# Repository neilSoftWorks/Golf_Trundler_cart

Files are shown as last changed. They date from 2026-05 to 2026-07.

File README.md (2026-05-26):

# Golf Cart Receiver (The Brain)

This firmware runs on the **ESP32-S3 SuperMini attached to the Hoverboard**. It acts as the "Software Defined" brain of the vehicle, managing motor logic, safety, and a professional diagnostic display.

## Key Features
*   **Transparent Driver Model:** The Hoverboard acts as a dumb driver; all mixing and tuning logic lives on the ESP32.
*   **Dynamic Tuning:** Adjust Torque (Amps) and Smoothing (Inertia) in real-time without re-flashing.
*   **Active Hill Hold:** Long-press STOP triggers an active PID-lock for rock-solid parking on slopes.
*   **Dual Mode:**
    1.  **Manual Mode:** Control speed/steer via integrated 5-button set.
    2.  **Remote Mode:** Broadcast mirror control from the handheld remote (ESP-NOW).
*   **Integrated UI:** 240x320 ST7789 display with high-quality GFX fonts and a professional battery footer.
*   **Safety First:**
    *   **Reverse Limit:** Hard-limited to speed '10' with visual orange warning.
    *   **Button Lock:** Speed setpoint frozen while Parked or Braked.
    *   **Watchdog:** Auto-stops if communication or remote link is lost.

## Wiring (See `gemini.md` for full details)
*   **UART:** GPIO 44 (RX) / 43 (TX) -> Hoverboard.
*   **Buttons:** FWD (12), REV (5), STOP (1), LEFT (10), RIGHT (11).
*   **Display (SPI):** SCK (6), MOSI (4), CS (7), DC (2), RST (3).

## How to Flash
See the comprehensive [FLASHING_GUIDE.md](../FLASHING_GUIDE.md) in the root directory for step-by-step instructions.

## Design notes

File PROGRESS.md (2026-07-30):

# Golf Trundler Progress (Cart Side)

## 1. Hardware Status
- [x] **Comms:** UART @ 19200 baud (GPIO 44/43).
- [x] **Control Mode:** **TRANSPARENT MOTOR DRIVER**.
    - ESP32 handles all Tank Mixing, Inversions, and Speed Synchronization.
    - Hoverboard Master/Slave updated to accept dynamic Mode, Torque, and Inertia.
- [x] **Display:** **INTEGRATED ST7789**. 
    - Professional GFX fonts (FreeSans, BigFont).
    - Battery Icon and Footer.
    - User / Dev dual-screen toggle.
- [x] **Manual Control:** 5-Button Integrated Set (GPIO 1, 5, 10, 11, 12).
- [x] **Wireless:** **UNIFIED CONTROL** (ESP-NOW Paired Link).
    - Hardcoded MAC Pairing established.
    - Dual-control merging (Logical OR of all buttons).

## 2. Firmware Features
### A. "Smart Manual" Mode
- **Active Hill Hold:** Long-press STOP triggers **Mode 1 (PID)** at speed 0 for absolute wheel lock.
- **Dynamic Tuning:** Current limit and Inertia are now adjustable via ESP32.
- **Visual Feedback:** Bold User Screen with color-coded directional warnings.
- **Dev Terminal:** Double-click STOP to view real-time RPM, Voltage, and Sync factors.
- **Beeper:** Reverse beep disabled.
- **Auto-Shutdown:** Disabled (unit stays active for long test sessions).

### B. Safety
- **Reverse Limit:** Hard-limited to user-speed "20" (-350 internal).
- **Forward Limit:** Hard-limited to user-speed "30" (525 internal).
- **Interlock:** Speed cannot be changed while Parked or Braked.
- **Remote Timeout:** Remote commands ignored if link lost for >1s.

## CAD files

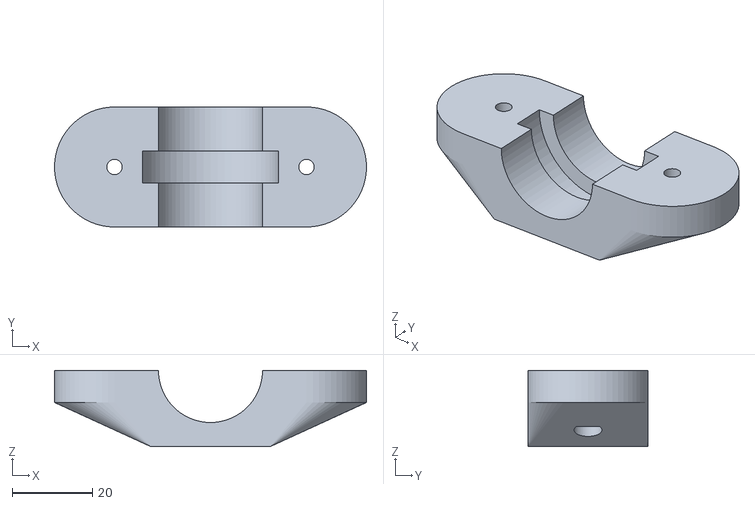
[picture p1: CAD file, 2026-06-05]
CAD/Clamp_B_Mount26.stl
78.0 x 30.0 x 19.0

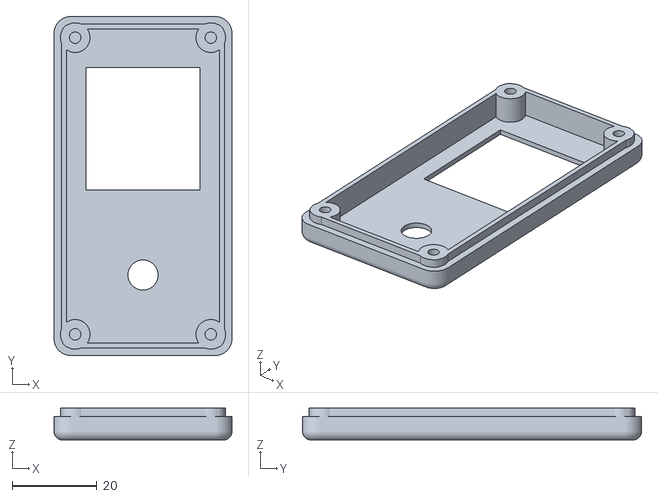
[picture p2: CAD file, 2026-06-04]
CAD/comboMount26T.stl
42.0 x 80.0 x 7.50

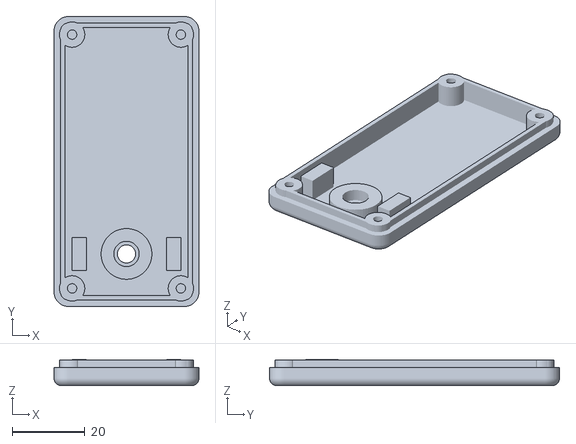
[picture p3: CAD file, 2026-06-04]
CAD/RemoteLid.stl
40.0 x 80.0 x 7.20

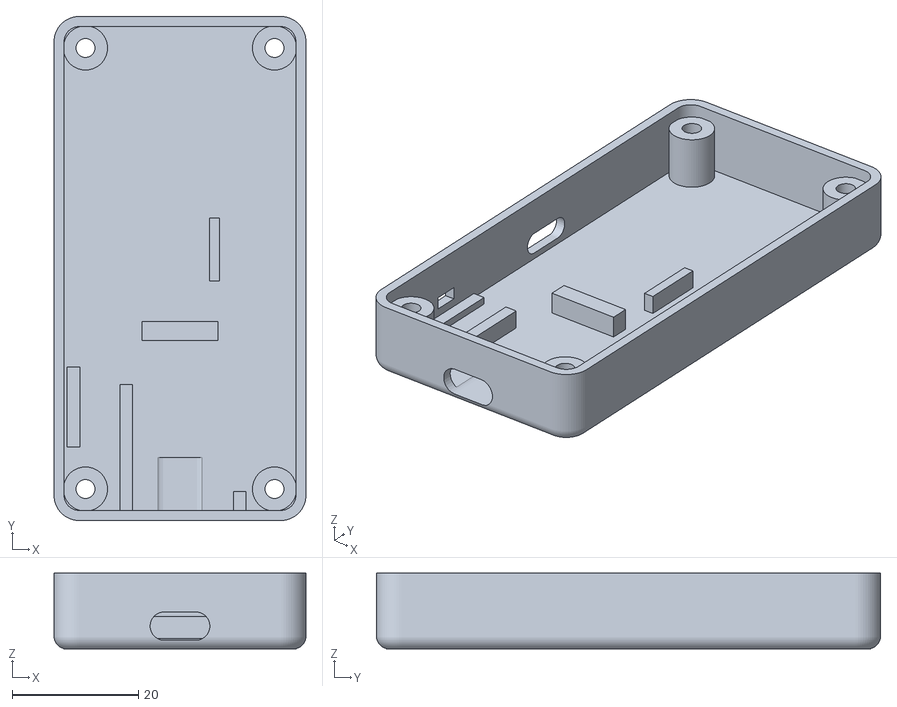
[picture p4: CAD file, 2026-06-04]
CAD/RemoteBase.stl
40.0 x 80.0 x 12.0

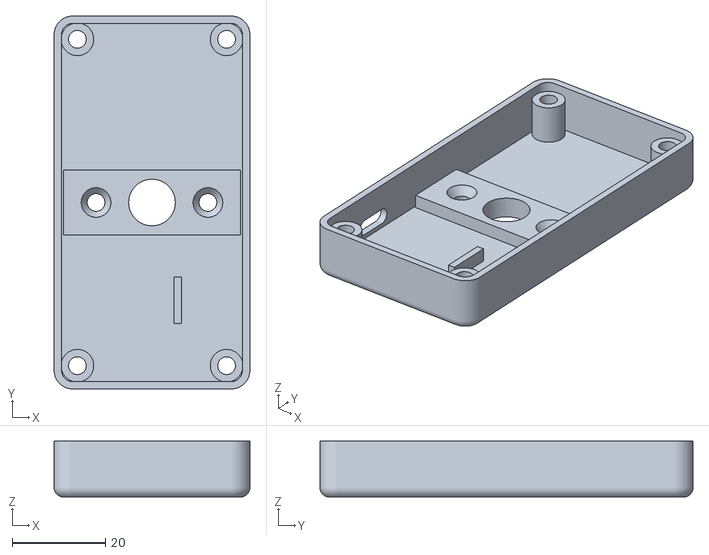
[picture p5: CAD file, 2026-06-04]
CAD/comboMount26B.stl
42.0 x 80.0 x 12.0

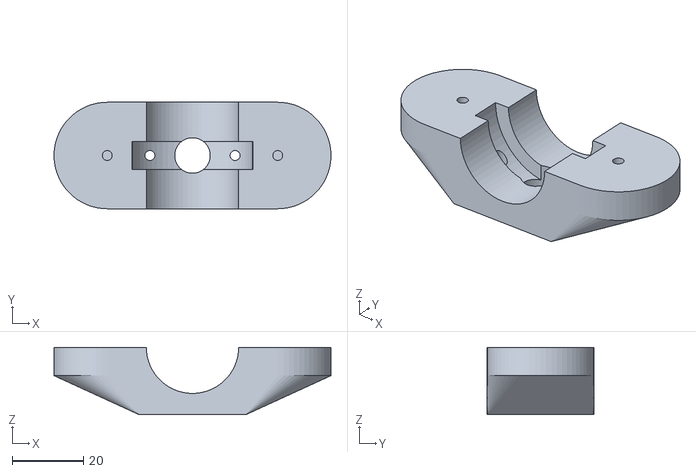
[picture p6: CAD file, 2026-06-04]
CAD/Clamp_T_Mount26.stl
78.0 x 30.0 x 19.0

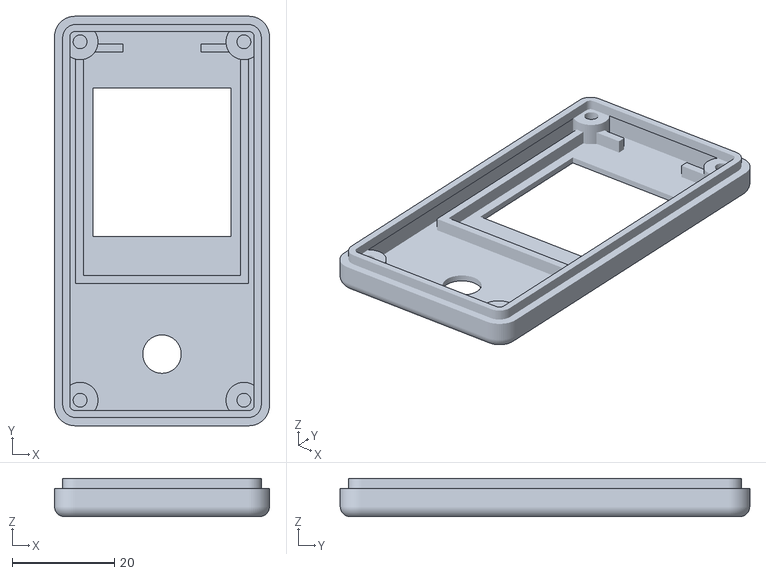
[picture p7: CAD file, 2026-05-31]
CAD/comboMount_lid.stl
42.0 x 80.0 x 7.50

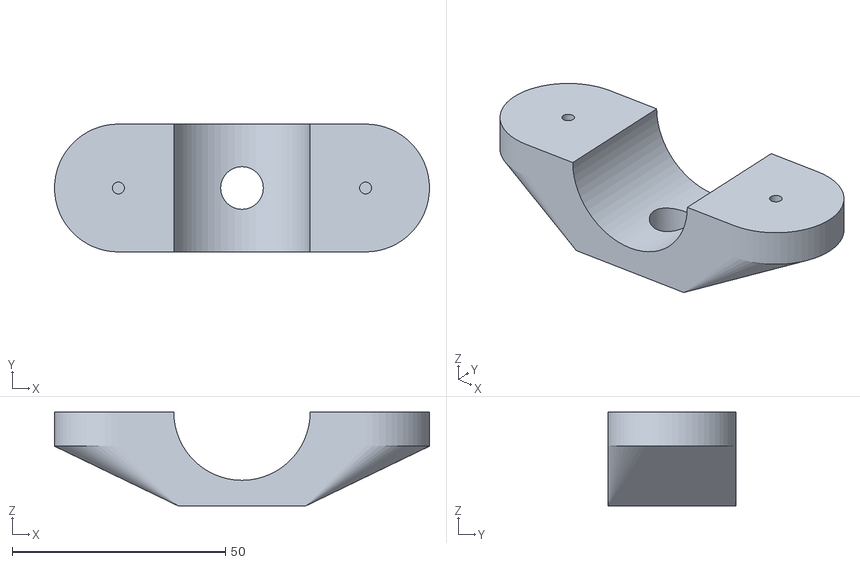
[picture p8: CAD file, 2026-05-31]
CAD/comboMount2.stl
88.0 x 30.0 x 22.0

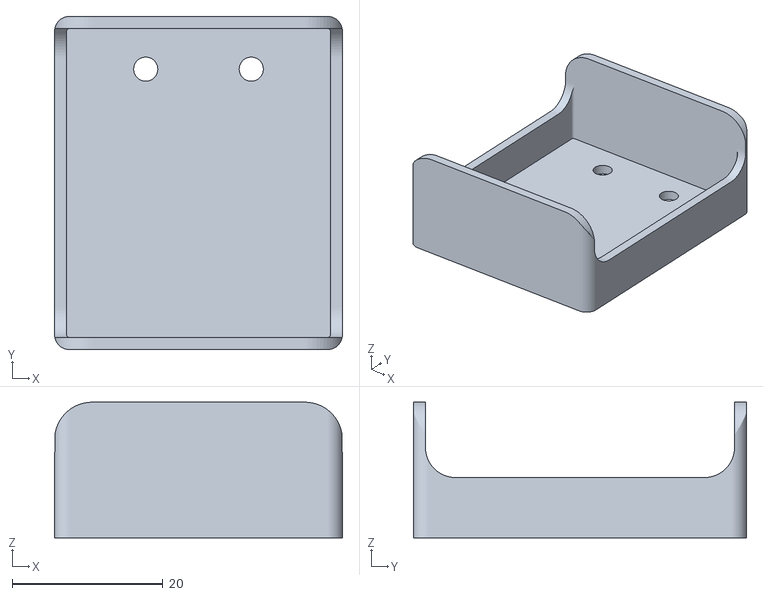
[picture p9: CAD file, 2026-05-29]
CAD/ShotScopeMount.stl
38.2 x 44.2 x 18.0

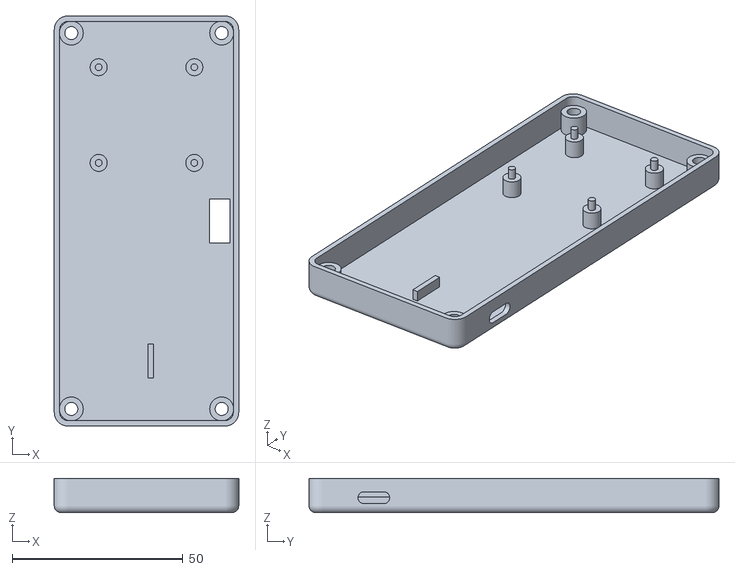
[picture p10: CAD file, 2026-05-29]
CAD/Cart_Controller_base.stl
54.0 x 120.0 x 10.0

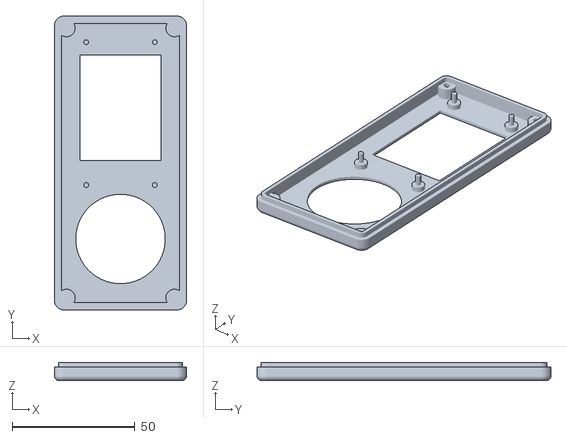
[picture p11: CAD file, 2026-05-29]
CAD/Cart_Controller_lid.stl
54.0 x 120.0 x 7.50

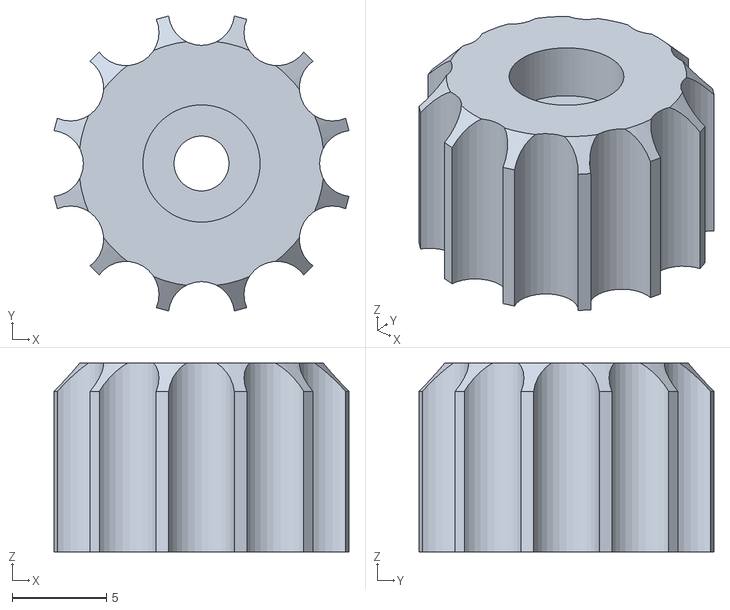
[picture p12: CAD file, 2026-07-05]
CAD/ThumbScrew.stl
15.6 x 15.6 x 10.0

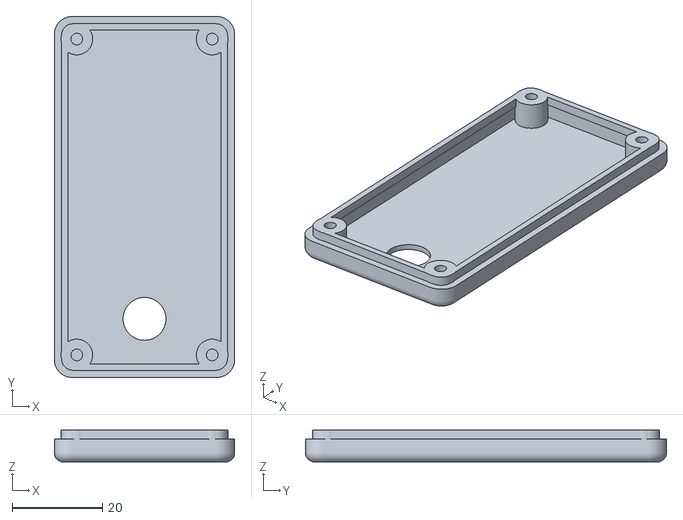
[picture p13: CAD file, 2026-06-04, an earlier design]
CAD/Archive/Remote80T.stl
40.0 x 80.0 x 7.00

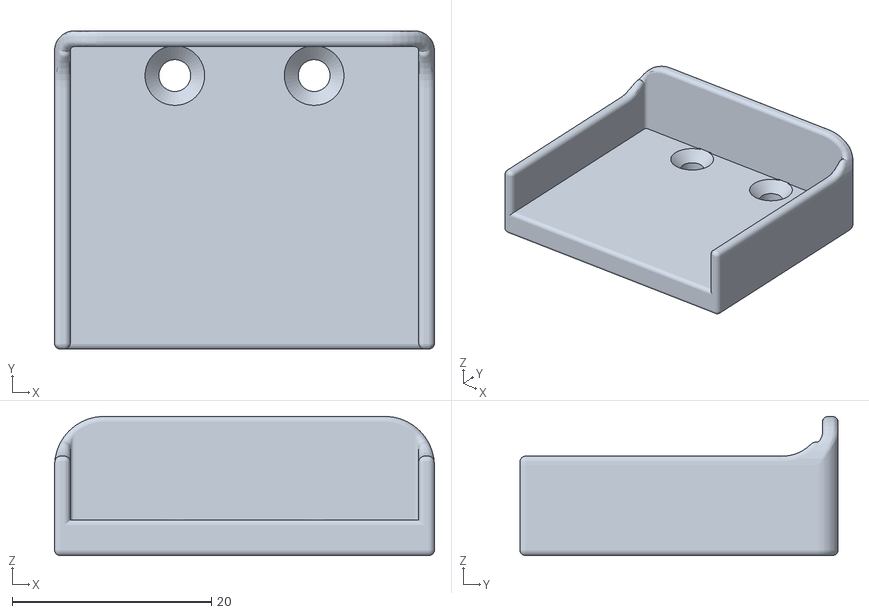
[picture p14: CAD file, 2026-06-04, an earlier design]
CAD/Archive/ShotScopeMount2.stl
38.2 x 32.0 x 14.0

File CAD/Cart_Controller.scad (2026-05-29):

// --- 1. PARAMETERS ---

// Which part to see?
part_to_show = "lid"; // [both, base, lid]
show_labels  = false;  

width  = 54;
length = 120; 
base_depth = 10;
lid_depth  = 5.5;

// --- WALL THICKNESS ---
wall = 1.6;          
lid_thickness = 1.2; 
gap  = 0.2;          
lip_wall = 1.2;      

// --- TFT CUTOUT ---
tft_width  = 33;
tft_height = 43;
tft_margin = 13; 

// --- TFT PEGS ---
peg_dia = 2;
peg_height = 6;
peg_foot_height = 2; 
peg_foot_dia    = 5; 

// --- NAV SWITCH (D-PAD) ---
nav_dia = 36.5;         
nav_y_center = 91.0;    

// --- NAV SWITCH MOUNTING (Veroboard - In Base) ---
nav_mount_spacing_x = 28.0; 
nav_mount_spacing_y = 28.0; 

nav_peg_dia = 2.0;       // Diameter of the pin going through the PCB
nav_peg_height = 3.0;    // Height of the pin 
nav_foot_dia = 5.0;      // Base pillar diameter
nav_foot_height = 5.0;   // ADJUST THIS to set how high the PCB sits off the floor!

// --- PORT CUTOUTS (Right Long Edge) ---
// 1. USB-C Port (Side Wall)
usbc_w = 9.3;
usbc_h = 3.5;
usbc_gap_from_floor = 1.0; 
usbc_y_pos = 19.0; 

// 2. Rectangular Floor Port 
floor_hole_length = 13.0; 
floor_hole_width  = 6.0;  
// Positioned automatically at length/2 (Centered)

// --- PORT BACKSTOPS ---
backstop_right_dist_from_wall = 24.1; 
backstop_right_length = 10; 
backstop_right_thick  = 1.6;  
backstop_right_height = 3;  

// Radii
corner_rad = 4;      
edge_rad   = 2;    

// Screw Dimensions (M3)
screw_dia = 3.2 + 0.6;       
screw_pilot = 2.7;     
screw_head_dia = 4.8 + 0.6; 
screw_head_height = 3; 
screw_pos_offset = 5;  

// View Control
explode_view = 25; 
cross_section = false; 

$fn = 50; 
overlap = 0.1; 
fuse_fix = 0.2; 

// --- 2. ASSEMBLY ---
difference() {
    union() {
        if (part_to_show == "base" || part_to_show == "both") {
            color("CornflowerBlue") base();
            if (show_labels) orientation_labels();
        }

        if (part_to_show == "lid" || part_to_show == "both") {
            z_pos = (part_to_show == "both") ? base_depth + explode_view : 0;
            rot_vec = (part_to_show == "lid") ? [180,0,0] : [0,0,0];
            
            translate([0, 0, z_pos]) 
                rotate(rot_vec)
                color("Orange") lid();
        }
    }
    
    if (cross_section) {
        translate([-5, -50, -50]) cube([100, 200, 200]);
    }
}

// --- 3. MODULES ---

module base() {
    difference() {
        union() {
            difference() {
                intersection() {
                    soft_box(width, length, base_depth + edge_rad, corner_rad, edge_rad);
                    cube([width, length, base_depth]);
                }
                translate([wall, wall, wall])
                    rounded_prism(width - 2*wall, length - 2*wall, base_depth, corner_rad - wall);
            }
            
            pillar_positions(base_depth - 2.6);
            usb_backstop_right(); 
            
            // Veroboard pillars moved here, pointing UP from the base
            nav_mount_pegs(); 
        }
        
        screw_locations("clearance");
        usb_cutouts(); 
    }
}

module lid() {
    difference() {
        union() {
            // A. Solid Lid Shell
            difference() {
                union() {
                     // Main Body
                    intersection() {
                        translate([0, 0, -edge_rad])
                            soft_box(width, length, lid_depth + edge_rad, corner_rad, edge_rad);
                        cube([width, length, lid_depth]);
                    }
                    
                    // The Lip
                    translate([wall + gap - fuse_fix, wall + gap - fuse_fix, -2]) 
                        rounded_prism(
                            width - 2*(wall + gap - fuse_fix), 
                            length - 2*(wall + gap - fuse_fix), 
                            2 + overlap, 
                            corner_rad - (wall - fuse_fix)
                        );
                }

                // Hollow Inside
                union() {
                    translate([wall + gap, wall + gap, -overlap])
                        rounded_prism(width - 2*(wall + gap), length - 2*(wall + gap), lid_depth - lid_thickness + overlap, corner_rad - (wall+gap));
                    
                    translate([wall + gap + lip_wall, wall + gap + lip_wall, -2.1])
                        rounded_prism(width - 2*(wall + gap + lip_wall), length - 2*(wall + gap + lip_wall), 2.1 + overlap, corner_rad - (wall + gap + lip_wall));
                }
            }
            
            pillar_positions(lid_depth);
            tft_pegs();
        }

        // TFT Cutout
        translate([
            (width - tft_width) / 2,                
            (wall + gap + lip_wall) + tft_margin,   
            -5                                      
        ])
        cube([tft_width, tft_height, 20]);  

        // Nav Switch Cutout
        nav_switch();

        screw_locations("pilot");
    }
}

// --- HELPER MODULES ---

module nav_switch() {
    // A single circular hole for the entire D-pad cap assembly
    translate([width/2, nav_y_center, -10])
        cylinder(h=30, d=nav_dia);
}

module nav_mount_pegs() {
    // Start at the floor of the base
    start_z = wall; 
    
    // Create a 2x2 grid of mounting pegs centered around the switch cutout
    for (x = [-nav_mount_spacing_x/2, nav_mount_spacing_x/2]) {
        for (y = [-nav_mount_spacing_y/2, nav_mount_spacing_y/2]) {
            
            translate([width/2 + x, nav_y_center + y, start_z])
                union() {
                    // The wide base pillar the PCB rests on
                    cylinder(h = nav_foot_height, d = nav_foot_dia);
                    
                    // The narrow pin that goes through the PCB hole
                    translate([0, 0, nav_foot_height - 0.01])
                        cylinder(h = nav_peg_height, d = nav_peg_dia);
                }
        }
    }
}

module usb_backstop_right() {
    x_pos = (width - wall) - backstop_right_dist_from_wall;
    y_pos = usbc_y_pos;
    z_pos = wall + (backstop_right_height / 2);
    
    translate([x_pos, y_pos, z_pos])
        cube([backstop_right_thick, backstop_right_length, backstop_right_height], center=true);
}

module usb_cutouts() {
    // 1. USB-C Pill Cutout (Side Wall)
    z_pos_usbc  = wall + usbc_gap_from_floor + (usbc_h / 2);
    translate([width, usbc_y_pos, z_pos_usbc])
        rotate([90, 0, 90]) usbc_shape_extruded();

    // 2. Rectangular Floor Cutout (Centered along the right edge)
    translate([width - wall - (floor_hole_width / 2) - 1, length / 2, 0])
        cube([floor_hole_width, floor_hole_length, 20], center=true);
}

module usbc_shape_extruded() {
    linear_extrude(20, center=true) 
        hull() {
            translate([-(usbc_w - usbc_h)/2, 0, 0]) circle(d=usbc_h, $fn=30);
            translate([(usbc_w - usbc_h)/2, 0, 0]) circle(d=usbc_h, $fn=30);
        }
}

module tft_pegs() {
    cutout_x = (width - tft_width) / 2;
    cutout_y = (wall + gap + lip_wall) + tft_margin;
    start_z = lid_depth - lid_thickness - overlap;
    
    peg_positions = [
        [2.5, tft_height + 10], 
        [tft_width - 2.5, tft_height + 10],
        [2.5, -5.3],
        [tft_width - 2.5, -5.3]
    ];
    
    for (pos = peg_positions) {
        translate([cutout_x + pos[0], cutout_y + pos[1], start_z])
            mirror([0,0,1])
            union() {
                cylinder(h = peg_height, d = peg_dia);
                cylinder(h = peg_foot_height, d = peg_foot_dia);
            }
    }
}

module pillar_positions(h) {
    positions = [
        [screw_pos_offset, screw_pos_offset], 
        [width-screw_pos_offset, screw_pos_offset], 
        [screw_pos_offset, length-screw_pos_offset], 
        [width-screw_pos_offset, length-screw_pos_offset]
    ];
    for(pos = positions) {
        translate([pos[0], pos[1], 0])
             cylinder(h=h, r=screw_pos_offset - wall + overlap); 
    }
}

module soft_box(w, l, h, c_rad, e_rad) {
    translate([e_rad, e_rad, e_rad])
        minkowski() {
            rounded_prism(w - 2*e_rad, l - 2*e_rad, h - 2*e_rad, c_rad - e_rad);
            sphere(r=e_rad);
        }
}

module rounded_prism(w, l, h, r) {
    hull() {
        translate([r, r, 0]) cylinder(h=h, r=r);
        translate([w-r, r, 0]) cylinder(h=h, r=r);
        translate([r, l-r, 0]) cylinder(h=h, r=r);
        translate([w-r, l-r, 0]) cylinder(h=h, r=r);
    }
}

module screw_locations(type) {
    positions = [
        [screw_pos_offset, screw_pos_offset], 
        [width-screw_pos_offset, screw_pos_offset], 
        [screw_pos_offset, length-screw_pos_offset], 
        [width-screw_pos_offset, length-screw_pos_offset]
    ];
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

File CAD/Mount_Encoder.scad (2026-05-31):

// --- PART SELECTOR ---
// 0 = Assembly View
// 1 = Top Housing (Blue) - Print Upside Down
// 2 = Bottom Clamp (Orange) - Print Flat
part_to_print = 0;

// --- Dimensions ---
handle_diam = 32;
clamp_width = 30;

// Spacing
extra_spacing = 13;     

// Electronics Box
box_w = 36;
box_l = 36;
box_h = 25;
box_wall = 3;
box_radius = 4;

// Screw Settings
screw_clearance_diam = 3.8; // Hole for screw shaft
pilot_hole_diam = 2.8;      // Hole for screw threads (in top part)

// --- NEW COUNTERBORE SETTINGS ---
screw_head_diam = 7.0;      // Requested 7mm
// The shelf is where the screw head touches. 
// Z=0 is the meeting line. Z=-5 means there is 5mm of plastic holding the clamp.
screw_head_shelf_z = -10.0;  

// Calculated screw position
screw_offset = (handle_diam/2) + extra_spacing; 

// Wing Thickness
wing_thick = 8;         

$fn = 60;

// --- Logic ---

if (part_to_print == 0) {
    // Assembly View
    translate([0,0,5]) Top_Housing();
    translate([0,0,-5]) Bottom_Clamp();
    
    // Hardware Preview
    %color("Red") rotate([0,90,0]) cylinder(d=handle_diam, h=100, center=true);
    
    // Show Screw Head Landing Spot (Green Disk)
    // This represents the flat surface the screw pushes against
    color("Lime") translate([0, screw_offset, -5 + screw_head_shelf_z]) cylinder(d=screw_head_diam, h=0.2);
    color("Lime") translate([0, -screw_offset, -5 + screw_head_shelf_z]) cylinder(d=screw_head_diam, h=0.2);
}
else if (part_to_print == 1) {
    rotate([180,0,0]) Top_Housing();
}
else if (part_to_print == 2) {
    Bottom_Clamp();
}

// --- Modules ---

module Top_Housing() {
    color("CornflowerBlue")
    difference() {
        hull() {
            translate([-box_w/2, -box_l/2, 0])
                Rounded_Block(box_w, box_l, box_h + box_wall, box_radius);
            
            translate([0, screw_offset, 0])
                cylinder(d=clamp_width, h=wing_thick, center=false); 
            translate([0, -screw_offset, 0])
                cylinder(d=clamp_width, h=wing_thick, center=false); 
            
             translate([-clamp_width/2, -handle_diam/2, 0])
                    cube([clamp_width, handle_diam, wing_thick]); 
        }

        // Hollow
        translate([-box_w/2 + box_wall, -box_l/2 + box_wall, -0.1])
            Rounded_Block(box_w - 2*box_wall, box_l - 2*box_wall, box_h, box_radius-1);
            
        // Handle Cutout
        translate([0,0,0])
            rotate([0,90,0]) 
            cylinder(d=handle_diam, h=clamp_width+50, center=true);
            
        // Pilot Holes (Blind)
        hole_depth = wing_thick + 5; 
        translate([0, screw_offset, -0.1])
            cylinder(d=pilot_hole_diam, h=hole_depth);
        translate([0, -screw_offset, -0.1])
            cylinder(d=pilot_hole_diam, h=hole_depth);
            
        // Encoder Hole
        translate([0,0, box_h + box_wall/2])
            cylinder(d=7.5, h=20, center=true);
    }
}

module Bottom_Clamp() {
    color("Orange")
    difference() {
        union() {
            hull() {
                translate([0, screw_offset, -wing_thick])
                    cylinder(d=clamp_width, h=wing_thick, center=false); 
                translate([0, -screw_offset, -wing_thick])
                    cylinder(d=clamp_width, h=wing_thick, center=false);
                
                translate([-clamp_width/2, -handle_diam/2 - 2, -20])
                    cube([clamp_width, handle_diam + 4, 20]);
            }
        }
            
        // Handle Cutout
        translate([0,0,0])
            rotate([0,90,0]) 
            cylinder(d=handle_diam, h=clamp_width+50, center=true);
            
        // 1. Through Holes
        translate([0, screw_offset, -50]) cylinder(d=screw_clearance_diam, h=100);
        translate([0, -screw_offset, -50]) cylinder(d=screw_clearance_diam, h=100);
        
        // 2. COUNTERBORE (The Flat Shelf)
        // We cut from way below (-50) UP TO the shelf level.
        // This guarantees a flat spot even if the hull is curved/angled.
        
        // Hole 1
        translate([0, screw_offset, -50])
            cylinder(d=screw_head_diam, h=50 + screw_head_shelf_z);
            
        // Hole 2
        translate([0, -screw_offset, -50])
            cylinder(d=screw_head_diam, h=50 + screw_head_shelf_z);
    }
}

module Rounded_Block(w, l, h, r) {
    hull() {
        translate([r, r, 0]) cylinder(r=r, h=h);
        translate([w-r, r, 0]) cylinder(r=r, h=h);
        translate([w-r, l-r, 0]) cylinder(r=r, h=h);
        translate([r, l-r, 0]) cylinder(r=r, h=h);
    }
}

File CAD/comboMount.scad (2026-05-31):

// --- PART SELECTOR ---
// 0 = Full Assembly View (Exploded)
// 1 = Base Box (Print flat)
// 2 = Lid (Print flat on top face)
// 3 = Bottom Clamp (Print flat on bottom)
// 4 = Top Clamp Adapter (Print flat on TOP face)
part_to_show = 0; 

// --- 1. ENCLOSURE PARAMETERS ---
width  = 42;
length = 80; 
base_depth = 12; 
lid_depth  = 5.5;

wall = 1.6;          
lid_thickness = 1.2; 
gap  = 0.2;          
lip_wall = 1.2;      

// --- 2. MOUNTING CLAMP PARAMETERS ---
handle_diam = 32;       
clamp_width = 30;       
extra_spacing = 13;     
wing_thick = 8;  

clamp_y_center = length / 2;    
clamp_height = (handle_diam / 2) + 6; 

screw_clearance_diam = 3.8; 
pilot_hole_diam = 2.8;      
screw_head_diam = 7.0;      
screw_offset = (handle_diam/2) + extra_spacing; 

// Box-to-Clamp Internal Mounting
box_mount_spacing = 24; 
box_mount_head_dia = 6.5; 
cable_hole_dia = 10.0;  

// --- 3. HARDWARE CUTOUTS ---
tft_pcb_w = 30.0;    
tft_pcb_l = 43.0;    
tft_screen_w = 27.0; 
tft_screen_l = 29.0; 
tft_margin_y = 4.0;  
tft_tolerance = 0.6; 
tft_screen_offset_y = 0.0; 

encoder_hole_dia = 7.5;     
encoder_y_center = 66.0;   

// --- 4. PORTS & BACKSTOPS ---
usbc_w = 9.3;
usbc_h = 3.5;
usbc_gap_from_floor = 1.0; 
usbc_y_pos = 19.0;  // Shifted away from the central mounting boss

backstop_dist_from_wall = 24.1; 
backstop_length = 10.0; 
backstop_thick  = 1.6;  
backstop_height = 3.0;  

// Radii & Box Screws
corner_rad = 4;      
edge_rad   = 2;      
box_screw_dia = 3.8;        
box_screw_pilot = 2.7;      
box_screw_head_dia = 5.4; 
box_screw_head_height = 3; 
box_pos_offset = 5;  

$fn = 60; 
overlap = 0.1; 

// --- ASSEMBLY LOGIC ---
if (part_to_show == 0) {
    translate([0, 0, clamp_height]) color("CornflowerBlue") base();
    
    translate([0, 0, clamp_height + base_depth + 15]) 
        rotate([180,0,0]) color("Orange") lid();
        
    color("DodgerBlue") top_clamp();
        
    translate([0, 0, -10]) color("DarkOrange") bottom_clamp();
        
    %color("Red") translate([width/2, clamp_y_center, 0]) 
        rotate([90,0,0]) cylinder(d=handle_diam, h=length + 20, center=true);
        
    %color("LimeGreen") translate([width/2, clamp_y_center, 0]) 
        cylinder(d=cable_hole_dia-1, h=clamp_height + base_depth + 5);
}
else if (part_to_show == 1) {
    base();
}
else if (part_to_show == 2) {
    rotate([180,0,0]) lid();
}
else if (part_to_show == 3) {
    bottom_clamp();
}
else if (part_to_show == 4) {
    rotate([180,0,0]) translate([0, 0, -clamp_height]) top_clamp();
}

// --- MODULES ---

module base() {
    difference() {
        union() {
            difference() {
                intersection() {
                    soft_box(width, length, base_depth + edge_rad, corner_rad, edge_rad);
                    cube([width, length, base_depth]);
                }
                translate([wall, wall, wall])
                    rounded_prism(width - 2*wall, length - 2*wall, base_depth, corner_rad - wall);
            }
            pillar_positions(base_depth - 2.6);
            
            translate([width/2, clamp_y_center, wall + 1.5])
                cube([box_mount_spacing + 14, 14, 3], center=true);
                
            usb_backstop_right();
        }
        box_screw_locations("clearance");
        usb_cutouts(); 
        box_mount_holes();
        
        translate([width/2, clamp_y_center, -5])
            cylinder(d=cable_hole_dia, h=base_depth + 10);
    }
}

module top_clamp() {
    translate([width/2, clamp_y_center, 0]) {
        difference() {
            hull() {
                translate([screw_offset, 0, 0]) cylinder(d=clamp_width, h=wing_thick); 
                translate([-screw_offset, 0, 0]) cylinder(d=clamp_width, h=wing_thick); 
                translate([0, 0, clamp_height - 1]) cube([clamp_width, clamp_width, 2], center=true);
            }
            
            rotate([90,0,0]) cylinder(d=handle_diam, h=clamp_width+50, center=true);
            
            translate([screw_offset, 0, -1]) cylinder(d=pilot_hole_diam, h=wing_thick);
            translate([-screw_offset, 0, -1]) cylinder(d=pilot_hole_diam, h=wing_thick);
            
            translate([box_mount_spacing/2, 0, clamp_height - 10]) cylinder(d=pilot_hole_diam, h=15);
            translate([-box_mount_spacing/2, 0, clamp_height - 10]) cylinder(d=pilot_hole_diam, h=15);
            
            translate([0, 0, -50]) cylinder(d=cable_hole_dia, h=100);
        }
    }
}

module bottom_clamp() {
    translate([width/2, clamp_y_center, 0]) {
        difference() {
            hull() {
                translate([screw_offset, 0, -wing_thick]) cylinder(d=clamp_width, h=wing_thick); 
                translate([-screw_offset, 0, -wing_thick]) cylinder(d=clamp_width, h=wing_thick);
                translate([0, 0, -clamp_height + 1]) cube([clamp_width, clamp_width, 2], center=true);
            }
                
            rotate([90,0,0]) cylinder(d=handle_diam, h=clamp_width+50, center=true);
            
            translate([screw_offset, 0, -50]) cylinder(d=screw_clearance_diam, h=100);
            translate([-screw_offset, 0, -50]) cylinder(d=screw_clearance_diam, h=100);
            
            cb_depth = 5;
            translate([screw_offset, 0, -clamp_height - 1]) cylinder(d=screw_head_diam, h=cb_depth + 1);
            translate([-screw_offset, 0, -clamp_height - 1]) cylinder(d=screw_head_diam, h=cb_depth + 1);
        }
    }
}

module lid() {
    difference() {
        union() {
            difference() {
                union() {
                    intersection() {
                        translate([0, 0, -edge_rad]) soft_box(width, length, lid_depth + edge_rad, corner_rad, edge_rad);
                        cube([width, length, lid_depth]);
                    }
                    translate([wall + gap - 0.2, wall + gap - 0.2, -2]) 
                        rounded_prism(width - 2*(wall + gap - 0.2), length - 2*(wall + gap - 0.2), 2 + overlap, corner_rad - (wall - 0.2));
                }
                union() {
                    translate([wall + gap, wall + gap, -overlap])
                        rounded_prism(width - 2*(wall + gap), length - 2*(wall + gap), lid_depth - lid_thickness + overlap, corner_rad - (wall+gap));
                    translate([wall + gap + lip_wall, wall + gap + lip_wall, -2.1])
                        rounded_prism(width - 2*(wall + gap + lip_wall), length - 2*(wall + gap + lip_wall), 2.1 + overlap, corner_rad - (wall + gap + lip_wall));
                }
            }
            pillar_positions(lid_depth);
            tft_cradle(); 
        }

        screen_cut_x = (width - tft_screen_w) / 2;
        screen_cut_y = (wall + gap + lip_wall) + tft_margin_y + ((tft_pcb_l - tft_screen_l)/2) + tft_screen_offset_y;
        
        translate([screen_cut_x, screen_cut_y, -5]) cube([tft_screen_w, tft_screen_l, 20]);  
        translate([width/2, encoder_y_center, -5]) cylinder(h=20, d=encoder_hole_dia);
        box_screw_locations("pilot");
    }
}

// --- HELPER MODULES ---

module usb_backstop_right() {
    x_pos = width - wall - backstop_dist_from_wall - (backstop_thick / 2);
    y_pos = usbc_y_pos;
    z_pos = wall + (backstop_height / 2);
    translate([x_pos, y_pos, z_pos]) cube([backstop_thick, backstop_length, backstop_height], center=true);
}

module box_mount_holes() {
    boss_z = wall + 3; 
    cone_h = 2.0;      
    
    translate([width/2 + box_mount_spacing/2, clamp_y_center, 0]) {
        translate([0,0,-1]) cylinder(d=screw_clearance_diam, h=base_depth + 2);
        translate([0,0, boss_z - cone_h]) cylinder(d1=screw_clearance_diam, d2=box_mount_head_dia, h=cone_h + 0.1);
        translate([0,0, boss_z]) cylinder(d=box_mount_head_dia, h=base_depth);
    }
    translate([width/2 - box_mount_spacing/2, clamp_y_center, 0]) {
        translate([0,0,-1]) cylinder(d=screw_clearance_diam, h=base_depth + 2);
        translate([0,0, boss_z - cone_h]) cylinder(d1=screw_clearance_diam, d2=box_mount_head_dia, h=cone_h + 0.1);
        translate([0,0, boss_z]) cylinder(d=box_mount_head_dia, h=base_depth);
    }
}

module tft_cradle() {
    pcb_w = tft_pcb_w + tft_tolerance;
    pcb_l = tft_pcb_l + tft_tolerance;
    wall_thick = 1.6;
    cradle_h = 2.5; 
    
    cradle_x = (width - pcb_w) / 2;
    cradle_y = (wall + gap + lip_wall) + tft_margin_y;
    start_z = lid_depth - lid_thickness;
    
    translate([cradle_x, cradle_y, start_z]) mirror([0,0,1]) difference() {
        translate([-wall_thick, -wall_thick, 0]) cube([pcb_w + 2*wall_thick, pcb_l + 2*wall_thick, cradle_h]);
        translate([0, 0, -1]) cube([pcb_w, pcb_l, cradle_h + 2]);
        translate([pcb_w/4, -wall_thick - 1, -1]) cube([pcb_w/2, wall_thick + 2, cradle_h + 2]);
    }
}
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

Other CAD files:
CAD/comboMount1.stl
CAD/comboMount_base.stl
CAD/Archive/comboMount26B.stl
CAD/Archive/Remote80B.stl
CAD/Cart_Remote.scad
CAD/Archive/Cart_Remote.scad
CAD/Archive/Remote.scad
CAD/Archive/Remote75.scad
CAD/Archive/Remote75T.stl
CAD/Archive/Remote75b.stl
CAD/Archive/Remote80.scad
CAD/Archive/RemoteB.stl
CAD/Archive/RemoteT.stl
CAD/Archive/ShotScopeMount.scad
CAD/Archive/ShotScopeMount2.scad
CAD/Archive/comboMount1.stl
CAD/Archive/comboMount26.scad
CAD/Archive/comboMount_lid.stl
CAD/Remote.scad
CAD/ShotScopeMount.scad
CAD/ThumbScrew.scad
CAD/comboMount26.scad

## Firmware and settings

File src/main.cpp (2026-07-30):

#include <Arduino.h>
#include <WiFi.h>
#include <esp_now.h>
#include <esp_wifi.h>
#include "AiEsp32RotaryEncoder.h"
#include "util.h"
#include "hoverserial.h"
#include "input.h" 
#include "TrundlerDisplay.h"
#include "communication.h"

// --- Config ---
#define HOVER_BAUD 19200
#define SEND_INTERVAL_MS 20  

// Hardware Serial for Hoverboard (C3 uses pins 20/21)
HardwareSerial HoverSerial(1); 
SerialHover2Server feedback;

// UI Object (CS=7, DC=2, RST=3) - SPI SCK=8, MOSI=10 are hardware-defined
TrundlerDisplay ui(TFT_CS, TFT_DC, TFT_RST);

// Encoder Object (Swapped DT and CLK to invert rotation direction)
AiEsp32RotaryEncoder encoder = AiEsp32RotaryEncoder(ENC_DT, ENC_CLK, ENC_SW, -1, 4);

InputState remoteInputs; 
CartData cartStatus;

bool hasRemote = false;
unsigned long lastRecvTime = 0;

// System States
bool manualActive = false;   
bool isCruiseMode = false;   
int16_t userSpeedLevel = 0;    // Discrete speed level (-20 to 30)
int16_t manualTargetSpeed = 0; 
int16_t manualCurrentSpeed = 0;
float slaveComp = 1.0; 
bool showDevScreen = false; 

// Software Cruise State
int16_t cruiseNudge = 0;

// Tuning Parameters
uint8_t curLimit = 15;  
uint8_t inertia = 10;   

uint8_t remoteMacAddress[6];
bool remotePeerAdded = false;

void onDataRecv(const uint8_t * mac, const uint8_t *incomingData, int len) {
  if (len == sizeof(InputState)) {
    memcpy(&remoteInputs, incomingData, sizeof(InputState));
    lastRecvTime = millis();
    if (!hasRemote) {
        Serial.println("Remote Link Established!");
        if (!remotePeerAdded) {
            esp_now_peer_info_t peerInfo;
            memset(&peerInfo, 0, sizeof(peerInfo));
            memcpy(peerInfo.peer_addr, mac, 6);
            peerInfo.channel = 1; 
            peerInfo.encrypt = false;
            if (esp_now_add_peer(&peerInfo) == ESP_OK) {
                memcpy(remoteMacAddress, mac, 6);
                remotePeerAdded = true;
            }
        }
    }
    hasRemote = true;
  } else {
    Serial.printf("!!! Size Mismatch: Expected %d, Recv %d\n", sizeof(InputState), len);
  }
}

void encoder_on_button_click() {
    static unsigned long lastClick = 0;
    if (millis() - lastClick < 300) return;
    lastClick = millis();
    
    manualActive = !manualActive;
    // For forward speeds, preserve the set speed level in memory so it can be resumed on next go.
    // Always reset to 0 when stopping from reverse (negative speed) for safety.
    if (!manualActive && userSpeedLevel < 0) {
        userSpeedLevel = 0;
        encoder.setEncoderValue(0);
        manualTargetSpeed = 0;
    }
}

void setup() {
  // --- 1. Safety Boot Sequence ---
  Serial.begin(115200);
  delay(3000); 
  Serial.println("\n\n=== TRUNDLER C3 16-PIN RECOVERY BOOT ===");
  
  // --- 1b. Thermal Management ---
  ledcSetup(0, 5000, 8); 
  ledcAttachPin(TFT_BLK, 0);
  ledcWrite(0, 128); 

  // --- 1c. Wifi/Radio Init ---
  WiFi.mode(WIFI_STA);
  WiFi.disconnect(); 
  WiFi.setSleep(false);
  esp_wifi_set_max_tx_power(56); 
  
  // Mandatory for ESP-NOW: Set Channel 1 to match the Remote
  esp_wifi_set_promiscuous(true);
  esp_wifi_set_channel(1, WIFI_SECOND_CHAN_NONE);
  esp_wifi_set_promiscuous(false);

  // Print MAC and Channel
  uint8_t mac[6];
  WiFi.macAddress(mac);
  uint8_t chan;
  wifi_second_chan_t sec;
  esp_wifi_get_channel(&chan, &sec);
  Serial.printf("MAC: %02X:%02X:%02X:%02X:%02X:%02X | CH: %d\n", 
      mac[0], mac[1], mac[2], mac[3], mac[4], mac[5], chan);

  // --- 2. Init Hardware ---
  Serial.println("Initializing TFT...");
  ui.begin();

  Serial.println("Initializing Encoder...");
  encoder.begin();
  encoder.setup([]{ encoder.readEncoder_ISR(); });
  encoder.setBoundaries(0, 30, false); 
  encoder.setAcceleration(0);

  initInput();

  // --- 3. Init Comms ---
  Serial.println("Initializing ESP-NOW...");
  if (esp_now_init() != ESP_OK) {
    Serial.println("ESP-NOW Init Failed");
  }
  esp_now_register_recv_cb(onDataRecv);

  Serial.println("Initializing Hoverboard Serial...");
  HoverSerial.begin(HOVER_BAUD, SERIAL_8N1, HOVER_SERIAL_RX, HOVER_SERIAL_TX); 
  
  Serial.println("System Ready.");
}

void loop() {
  static unsigned long lastSend = 0;
  // --- 1. Inputs ---
  InputState localInputs = readInput();
  
  // Timeout Remote
  if (hasRemote && (millis() - lastRecvTime > 1000)) {
      memset(&remoteInputs, 0, sizeof(remoteInputs));
      hasRemote = false;
  }

  // --- 2. Process Commands ---
  // A. Local Encoder
  if (encoder.encoderChanged()) {
      userSpeedLevel = encoder.readEncoder();
      Serial.printf("Speed Level: %d\n", userSpeedLevel);
  }

  if (encoder.isEncoderButtonClicked()) {
      encoder_on_button_click();
      Serial.printf("Drive Toggle: %s\n", manualActive ? "ON" : "OFF");
  }

  // B. Remote
  static unsigned long lastRemoteAction = 0;
  static bool lastRemoteStopState = false;

  if (hasRemote) {
      // Remote can only change speed when active/driving (for safety when stopped)
      if (manualActive && (millis() - lastRemoteAction > 200)) {
          if (remoteInputs.fwd) { 
              userSpeedLevel = CLAMP(userSpeedLevel + 1, -20, 30); 
              encoder.setEncoderValue(userSpeedLevel);
              lastRemoteAction = millis();
          }
          if (remoteInputs.rev) { 
              userSpeedLevel = CLAMP(userSpeedLevel - 1, -20, 30); 
              encoder.setEncoderValue(userSpeedLevel);
              lastRemoteAction = millis();
          }
      }

      if (remoteInputs.stop && !lastRemoteStopState) {
          // Ignore STOP button if we are actively steering (holding Left or Right) on the remote
          if (!remoteInputs.left && !remoteInputs.right) {
              encoder_on_button_click();
          }
      }
      lastRemoteStopState = remoteInputs.stop;
  }

  // Merge Steering (Remote Only) with Dynamic Bias based on speed to overcome grass resistance
  int16_t steerBias = 110;
  if (abs(manualCurrentSpeed) > 100) {
      steerBias = 110 + (abs(manualCurrentSpeed) - 100) * 0.4f;
      if (steerBias > 190) steerBias = 190;
  }
  int16_t turnSteer = remoteInputs.left ? -steerBias : (remoteInputs.right ? steerBias : 0);

  // --- 3. Unified Speed Mapping ---
  if (!manualActive) {
      manualTargetSpeed = 0;
  } else {
      manualTargetSpeed = userSpeedLevel * 17.5f; 
  }

  // --- 4. Ramping ---
  static unsigned long lastMoveRamp = 0;
  if (millis() - lastMoveRamp > 50) {
      lastMoveRamp = millis();
      int16_t target = manualTargetSpeed;
      if (manualCurrentSpeed < target) manualCurrentSpeed += 5;
      else if (manualCurrentSpeed > target) manualCurrentSpeed -= 5;
  }
  
  int16_t driveSpeed = manualCurrentSpeed;

  // --- 5. SOFTWARE CRUISE CONTROL ---
  static unsigned long lastCruiseAdjust = 0;
  if (manualActive && isCruiseMode && abs(manualTargetSpeed) > 50 && turnSteer == 0 && (millis() - lastCruiseAdjust > 100)) {
      lastCruiseAdjust = millis();
      int16_t targetRPM = abs(manualTargetSpeed) * 1.5; 
      int16_t actualRPM = (abs(cartStatus.speedL) + abs(cartStatus.speedR)) / 2;
      if (actualRPM < targetRPM - 15) cruiseNudge += 2;
      else if (actualRPM > targetRPM + 15) cruiseNudge -= 2;
      cruiseNudge = constrain(cruiseNudge, -50, 100); 
  } else if (!isCruiseMode || !manualActive) {
      cruiseNudge = 0;
  }

  // --- 4. Governor ---
  static unsigned long lastCompAdjust = 0;
  if (manualActive && !isCruiseMode && abs(driveSpeed) > 100 && turnSteer == 0 && (millis() - lastCompAdjust > 200)) {
      lastCompAdjust = millis();
      int16_t absL = abs(cartStatus.speedL);
      int16_t absR = abs(cartStatus.speedR);
      if (absR > absL + 20) slaveComp -= 0.002; 
      else if (absR < absL - 20) slaveComp += 0.002; 
      slaveComp = constrain(slaveComp, 0.7, 1.3); 
  }
  
  int16_t finalSpeed = driveSpeed;
  if (isCruiseMode && finalSpeed != 0) {
      if (finalSpeed > 0) finalSpeed += cruiseNudge;
      else finalSpeed -= cruiseNudge;
  }

  int16_t speedL = -(finalSpeed - turnSteer);
  int16_t speedR = (finalSpeed + turnSteer) * slaveComp; 

  uint8_t hoverMode = (manualActive && isCruiseMode) ? 1 : 0;
  
  uint8_t controlState = STATE_BATT_ONLY;
  if (!manualActive || (manualTargetSpeed == 0 && manualCurrentSpeed == 0 && turnSteer == 0)) {
      controlState = STATE_DISABLE;
  }

  // --- 7. RX Telemetry ---
  if (Receive(HoverSerial, feedback)) {
      cartStatus.voltage = feedback.iVolt / 100.0;
      cartStatus.speedL = feedback.iSpeedL;
      cartStatus.speedR = feedback.iSpeedR;
      cartStatus.odom = feedback.iOdomL;
  }

  // --- 8. UI Update ---
  uint8_t rBatt = hasRemote ? remoteInputs.vBatt : 0;
  ui.update(cartStatus, userSpeedLevel, turnSteer, slaveComp, manualActive, isCruiseMode, showDevScreen, hasRemote, rBatt, curLimit, inertia);

  // --- 9. TX Transmission ---
  if (millis() - lastSend > SEND_INTERVAL_MS) {
      lastSend = millis();
      HoverSend(HoverSerial, speedL, speedR, controlState, controlState, hoverMode, curLimit, inertia);
  }

  // --- 10. Send Telemetry back to Remote ---
  static unsigned long lastTelemetrySend = 0;
  if (hasRemote && remotePeerAdded && (millis() - lastTelemetrySend > 100)) {
      lastTelemetrySend = millis();
      cartStatus.isManual = manualActive;
      cartStatus.cmdSpeed = manualTargetSpeed;
      esp_now_send(remoteMacAddress, (uint8_t *) &cartStatus, sizeof(cartStatus));
  }
}

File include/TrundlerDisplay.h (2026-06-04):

#ifndef TRUNDLER_DISPLAY_H
#define TRUNDLER_DISPLAY_H

#include <Arduino.h>
#include <Adafruit_GFX.h>
#include <Adafruit_ST7735.h>
#include <Fonts/FreeSans9pt7b.h>
#include <Fonts/FreeSans12pt7b.h>
#include <Fonts/FreeSans18pt7b.h>
#include <Fonts/FreeSans24pt7b.h>
#include "BigFont.h"
#include "communication.h"
#include "input.h"

class TrundlerDisplay {
public:
    TrundlerDisplay(int cs, int dc, int rst);
    void begin();
    void update(const CartData &stats, int16_t targetSpeed, int16_t currentSteer, float slaveComp, bool active, bool isCruise, bool devMode, bool hasRemote, uint8_t remoteBatt, uint8_t curLimit, uint8_t inertia);

private:
    Adafruit_ST7735 tft;
    unsigned long _lastUpdate = 0;

    // State for flicker reduction
    float _lastVolt = -1.0;
    int16_t _lastSpeedL = -999, _lastSpeedR = -999;
    int16_t _lastTarget = -999;
    int16_t _lastSteer = -999;
    float _lastComp = -1.0;
    uint8_t _lastLimit = 0, _lastInertia = 0;
    bool _lastActive = true; // Set to true to force 'Stopped' redraw on boot
    bool _lastCruise = false;
    bool _lastDevMode = false;
    bool _lastRemote = false;
    uint8_t _lastRemoteBatt = 0;

    void drawHeader();
    void drawFooter(float voltage, bool hasRemote, uint8_t remoteBatt);
    void drawUserScreen(const CartData &stats, int16_t targetSpeed, int16_t currentSteer, bool active);
    void drawDevScreen(const CartData &stats, int16_t targetSpeed, int16_t currentSteer, float slaveComp, bool active, bool isCruise);
    void drawBattery(int x, int y, float voltage);
    void drawRemoteIcon(int x, int y, bool connected, uint8_t remoteBatt);
    void drawSteeringArrows(int16_t currentSteer);

    const uint16_t C_BLACK   = 0x0000;
    const uint16_t C_WHITE   = 0xFFFF;
    const uint16_t C_GREY    = 0x2104; 
    const uint16_t C_GREEN   = 0x07E0;
    const uint16_t C_RED     = 0xF800;
    const uint16_t C_YELLOW  = 0xFFE0;
    const uint16_t C_CYAN    = 0x07FF;
    const uint16_t C_ORANGE  = 0xFC00;
};

#endif

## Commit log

2026-01-25 Add initial implementation of Golf Cart firmware with input handling, LED control, and communication protocols
2026-06-04 ver2- ok
    [.kicad_sch, .kicad_sch.kicad_sch, Cart_Controller.scad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]
2026-07-30 fix: max speed, turns etc
    [main.cpp]
